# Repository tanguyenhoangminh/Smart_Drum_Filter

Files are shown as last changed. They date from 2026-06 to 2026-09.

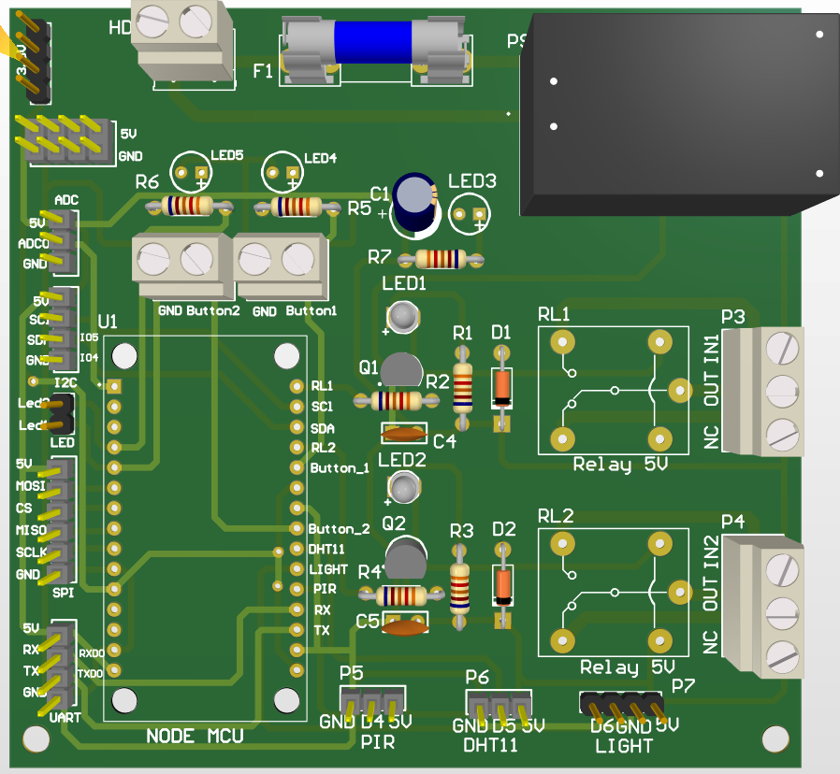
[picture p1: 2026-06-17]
ESP8266_Board/3D_ESP8266.PNG

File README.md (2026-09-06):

With the increasing demand for seafood consumption worldwide, the concept of Aquaculture is increasing, and the need to sustain the quality of water in the RAS has therefore emerged to be a challenge. Of the different types used, the RDF is identified to be one of the most efficient and effective mechanical filters used to remove suspended matter. Yet, the most efficient ones are relatively pricey, and there are no open-source options currently available for the small-scale implementation that the project addresses. The project, therefore, aims to design and implement the Smart Rotary Drum Filter and IoT-Based Control System. The system will make use of the ESP32 microcontroller, which will enable the automated backwashing process depending upon the real-time levels obtained from sensors and the programmed timer. Moreover, the system will also enable remote controlling and monitoring through the use of a mobile app, thereby increasing efficiency and minimizing the manpower aspect.

Keywords: RAS, RDF, Suspended Solids Removal, IoT-based Control, ESP32 Microcontroller, Automated Backwash, Remote Monitoring.

Results: https://drive.google.com/drive/folders/11fJMgWJ-M6j9aROdzN4QvXYW24VE6Z2o?usp=sharing

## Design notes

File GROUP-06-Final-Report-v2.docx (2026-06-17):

VIETNAM NATIONAL UNIVERSITY – HO CHI MINH CITY

INTERNATIONAL UNIVERSITY

SCHOOL OF ELECTRICAL ENGINEERING

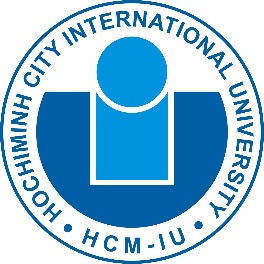
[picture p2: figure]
20070526074003!Logo-HCMIU

CAPSTONE DESIGN 2

SMART DRUM FILTER

Submitted By Group 06:

ta nguyen hoang minh - eeeeiu22084

le duc minh - eeeeiu22074

le Huu thang - eeeeiu22081

vuong thanh tung - eeeeiu22079

nguyen van vinh - eeaciu22174

Ho chi minh city, vietnam
May 26

SMART DRUM FILTER

SUBMITTED BY

TẠ NGUYỄN HOÀNG MINH – EEEEIU22084

LÊ ĐỨC MINH – EEEEIU22074

LÊ HỮU THẮNG – EEEEIU22081

VƯƠNG THANH TÙNG – EEEEIU22079

NGUYỄN VĂN VĨNH – EEACIU22174

Under the guidance and approval of the committee, and approved by its members, this report has been accepted as part of the requirements for Capstone Design 2.

Approved by:

________________________________
Chairperson

________________________________
Committee member

________________________________Committee member

________________________________
Committee member

________________________________
Committee member

________________________________
Committee member

# HONESTY DECLARATION

We, the undersigned members of Group 06, would like to declare that, apart from the acknowledged references, this report does not use language, ideas, or other original material from anyone else; and has not been previously submitted to any other educational or research programs or institutions. We fully understand that any content in this report that contradicts the above statement will automatically lead to the rejection of our Capstone Design 2 project by the School of Electrical Engineering, International University – Vietnam National University Ho Chi Minh City.

Date: 29/05/2026

Full name | Student ID | Signature
Ta Nguyen Hoang Minh | EEEEIU22084 | __________________
Le Duc Minh | EEEEIU22074 | __________________
Le Huu Thang | EEEEIU22081 | __________________
Vuong Thanh Tung | EEEEIU22079 | __________________
Nguyen Van Vinh | EEACIU22174 | __________________

# TURNITIN DECLARATION

Names of the students: Ta Nguyen Hoang Minh, Le Duc Minh, Le Huu Thang, Vuong Thanh Tung, Nguyen Van Vinh

Date: 29/05/2026

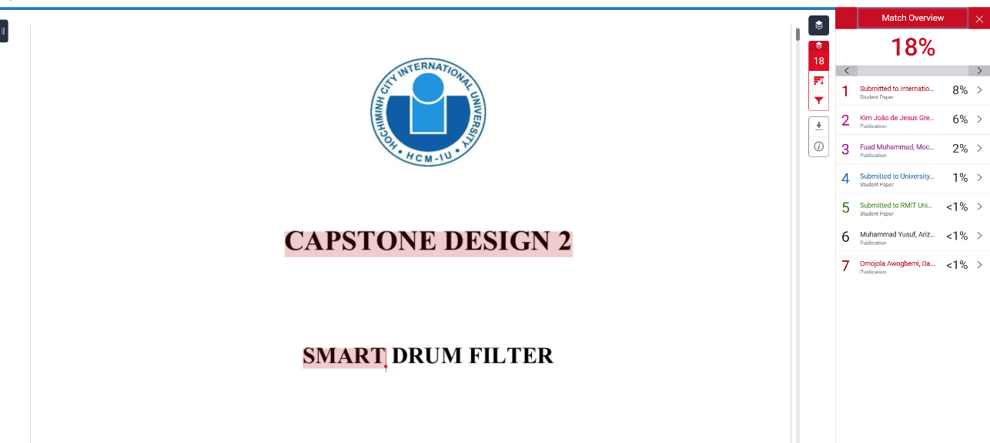
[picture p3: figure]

Advisor Signature Group Leader Signature

(on behalf of the group)

(Signature) (Signature)

__________________ __________________

M. Eng. Vo Minh Thanh Ta Nguyen Hoang Minh

Date: 29/05/2026 Date: 29/05/2026

# ACKNOWLEGMENTS

We, the members of Group 06, would like to express our sincere gratitude to M. Eng. Vo Minh Thanh for his invaluable guidance, encouragement, and support throughout the completion of our Capstone Design 2 project. His professional mentorship and insightful feedback consistently inspired us to improve and overcome challenges during the development process.

We also wish to thank the faculty and staff of the School of Electrical Engineering, International University – VNU-HCM, for providing us with the academic foundation and resources to carry out this project successfully.

# TABLE OF CONTENTS

# LIST OF TABLES

# LIST OF FIGURES

# ABBREVIATIONS AND NOTATIONS

AC Alternative Current

AES Advanced Encryption Standard

AP Access Point

BOD Biochemical Oxygen Demand

DC Direct Current

FAO Food and Agriculture Organization of the United Nations

GPIO General Purpose Input/Output

H Height

HTTP Hypertext Transfer Protocol

IoT Internet of Things

L Length

NAT Network Address Translation

PCB Printed Circuit Board

PSK Pre-Shared Key

RAS Rotary Aquaculture System

RDF Rotary Drum Filter

RL Relay

VAC Root-mean-square Voltage

W Width

Wi-Fi Wireless Fidelity

WPA Wi-Fi Protected Access

# ABSTRACT

With the increasing demand for seafood consumption worldwide, the concept of Aquaculture is increasing, and the need to sustain the quality of water in the RAS has therefore emerged to be a challenge. Of the different types used, the RDF is identified to be one of the most efficient and effective mechanical filters used to remove suspended matter. Yet, the most efficient ones are relatively pricey, and there are no open-source options currently available for the small-scale implementation that the project addresses. The project, therefore, aims to design and implement the Smart Rotary Drum Filter and IoT-Based Control System. The system will make use of the ESP32 microcontroller, which will enable the automated backwashing process depending upon the real-time levels obtained from sensors and the programmed timer. Moreover, the system will also enable remote controlling and monitoring through the use of a mobile app, thereby increasing efficiency and minimizing the manpower aspect.

Keywords: RAS, RDF, Suspended Solids Removal, IoT-based Control, ESP32 Microcontroller, Automated Backwash, Remote Monitoring.

# CHAPTER I - INTRODUCTION

In this chapter, there are three main sections: Issue, Problem Statements, Goal and Objectives. The first section considers the current problem concerned, the second section provides solutions for the first section, and the last one gives out expected goal and objectives needed to be carried out to complete the goal.

## 1. Issue

This part will analyse the causes of water pollution issues in aquaculture, which lead to the aquatic species mortality such as shrimp, fish....

### 1.1. The causes of water pollution in aquaculture

Aquaculture, the farming of aquatic organisms, has been the agro-industrial activity with the highest growth rate worldwide in the last four decades [1]. From 1970 to 2008 the production of aquaculture organisms grew at a rate of 8.3% per year, compared to less than 2% of fisheries, and 2.9% of livestock [1]. The annual aquaculture production is at present over 60 million tons (including marine plants), with an approximate value of 85 billion dollars. The FAO report (Fig.1) revealed that the world population increased by 6.3% from 2004 to 2009, whereas the production of aquatic organisms by aquaculture increased by 31.5% in the same period [1].

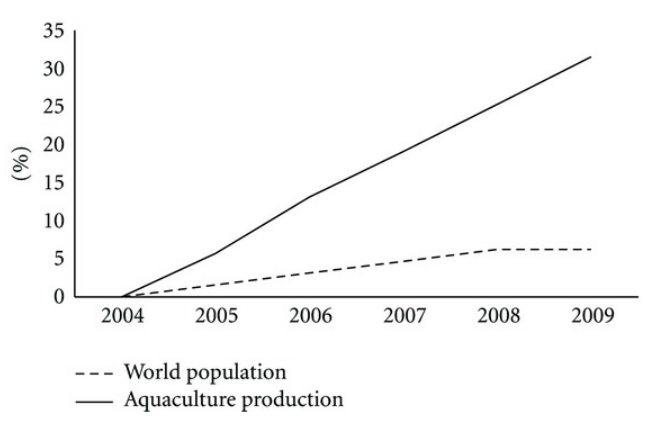
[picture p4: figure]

Figure 1: Compares the percentage of annual increase of world population and aquaculture production, considering year 2004 as the basepoint [1]

In recent years, fisheries and aquaculture production has reached record levels, with total production from 2022 reaching 223.2 million tonnes, of which aquaculture for the first time surpassed natural fishing, reaching 130.9 million tonnes and accounting for more than half of the total aquatic animal production [2]. This growth reflects the increasingly important role of aquaculture in meeting global food and nutrition needs, as per capita consumption has increased at 9.1 kg/year (1961) up to 20.7 kg/year (2022) [2]. However, developing rapidly in aquaculture also led to many factors many factors causing environmental changes on an increasingly large and diverse scale.

Waste from aquaculture includes sludge containing feces from aquatic species such as shrimp and fish, decaying and decomposed leftover feed, residues of materials used in aquaculture such as chemicals, lime and minerals like diatomite, dolomite, and sulfuric deposits, and toxic substances found in acidic soil. This waste is a product of anaerobic decomposition in water, and includes sediment deposited in aquaculture ponds during cleaning and dredging. Farming models with high stocking densities, such as intensive and industrial farming, generate even larger amounts of waste and have a greater impact on environmental pollution [3].

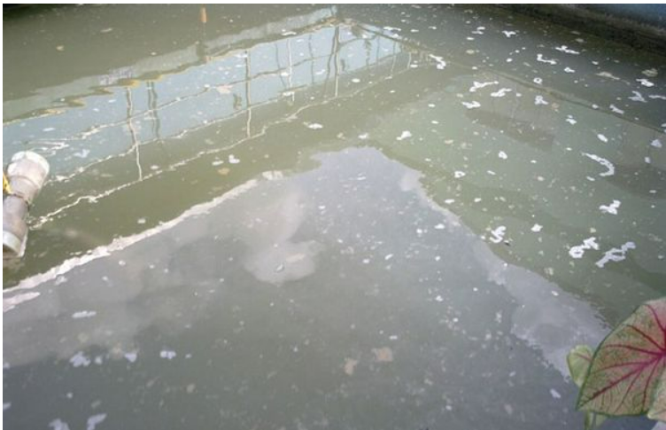
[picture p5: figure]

Some research results show that only 17% of the dry weight of feed supplied to aquaculture ponds is converted into biomass; the rest is released into the environment as manure and decaying excess organic matter [3]. For industrial ponds, waste can contain over 45% nitrogen and 22% other organic matter [3]. High levels of nitrogen and phosphorus in the waste cause eutrophication, leading to the growth of toxic algae in aquaculture environments [3]. This waste spreads rapidly in cage fish farming systems on rivers, and in cage fish farming in flooded wetlands... along with the spread of sediment, which can cause environmental pollution and aquatic diseases [3]. Besides that, the external environmental factors such as weather, waste from industrial production and processing, and domestic wastewater from residential and urban areas also contribute to affecting water quality in aquaculture, leading to more serious environmental pollution and causing significant economic and ecological damage.

Figure 2: Aquaculture ponds showing signs of organic pollution: turbid water, floating scum, reflecting surrounding construction [3].

The consequence of poor water quality and pollution include mass fish and shrimp mortality in coastal areas, which has occurred for many years. This has led to many shrimp farmers and some large-scale shrimp farming businesses to face financial ruin due to debt and bankruptcy. Furthermore, when seafoods get diseased, the consumers have to face with some risks such as exposure to antibiotic residues, antibiotic-resistant bacteria, and reduced nutritional quality. This not only affect human health, but also contributes to antibiotic resistance, and reduce confidence in the safety of food from sea.

### 1.2. The problem with water pollution in aquaculture

#### 1.2.1. Waste generation and treatment in aquaculture

Aquaculture systems generate significant amounts of biological waste, primarily from leftover feed, fish feces, and dissolved nutrients derived from feed and fish metabolism. According to A. B. Dauda, A. Ajadi, A. S. Tola-Fabunmi, and A. O. Akinwole, fish feces contain 3.6–35% Nitrogen (N) and 15–70% Phosphorus (P), while excretory products contribute an additional 37–72% N and 1–62% P [4]. These waste components accumulate in aquaculture ponds as organic-rich sediments and dissolved nutrient loads [4]. The accumulation of these substances increases BOD, disrupts water chemistry, and leads to oxygen depletion [4]. It also causes changes in microbial and plankton populations, increasing the risk of eutrophication and degrading pond bottom quality [4]. These changes negatively affect fish health, reduce pond productivity, and impair ecosystem services [4]. Although farmed fish can tolerate certain nutrient concentrations, the discharge of untreated wastewater into natural water sources can seriously affect surrounding aquatic life [4].

#### 1.2.2. External factors affecting the water environment in aquaculture

Besides internal waste from the farming system, aquaculture is also seriously affected by external factors such as industrial, agricultural, and domestic wastewater, and climate change. These sources of waste often carry heavy metals, toxic chemicals, pesticides, and organic matter, altering environmental parameters such as pH, salinity, and dissolved oxygen content, thereby degrading water quality in the ponds.

Agricultural waste, including pesticides, chemical fertilizers, and herbicides, can be washed into ponds, poisoning aquatic organisms [5]. If not treated promptly, these chemicals can cause mass mortality and degrade the farming environment [5].

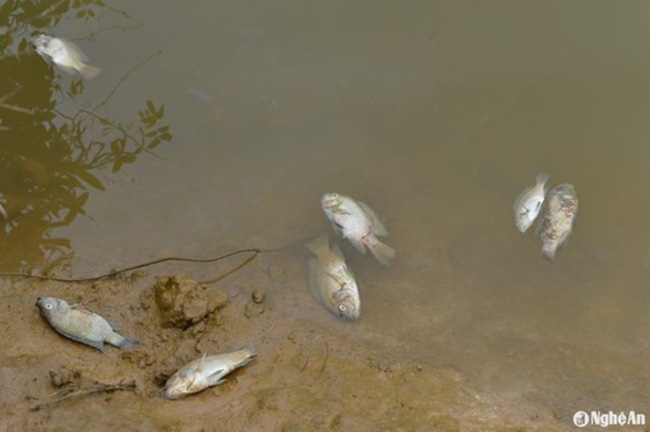
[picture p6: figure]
Ô nhiễm môi trường nước làm tôm cá chết.

Industrial wastewater from food processing, seafood processing, paper, and dyeing factories often contain heavy metals, toxic chemicals, and organic matter. In Hanoi, it has been observed that approximately 350,000–400,000 m³ of wastewater and over 1,000 m³ of solid waste are discharged daily, but only about 10% is treated [6]. The remainder is discharged directly into rivers and streams, causing serious pollution and leading to mass fish deaths in West Lake, affecting six inner-city districts [6]. In Ho Chi Minh City, the Thanh Luong industrial cluster is a prime example, with approximately 500,000 m³ of wastewater per day from detergent, paper, and dye factories [6].

Figure 3: Fish dead by water pollution in aquaculture [6]

Climate change is also a worrying external factor. Changes in temperature, pH, and dissolved oxygen levels in water exceed the tolerance threshold of aquatic life, causing stress or death [7]. Simultaneously, these factors increase the toxicity of certain compounds such as NH₃, H₂S, NO₂, etc., creating favourable conditions for disease development [7]. Without close monitoring and the application of appropriate technical measures, the risk of disease outbreaks and spread is very high, leading to mass fish deaths and water pollution in aquaculture ponds due to decomposing carcasses.

## 2. Problem Statement

To solve one part of these problems: how to remove the waste generated during aquaculture. Our group will design a drum filter system that can effectively remove solid waste such as fish feces, leftover feed, and organic matter before they accumulate and degrade water quality.

## 3. Goal And Objectives

### a. Goal

To design and develop a smart drum filter system capable of remote control and monitoring to optimize operational costs.

### b. Objectives

  - Objective 1:

To design the overall system architecture, focus on the mechanical structure (drum, supporting frame, and water flow system…).

- Task 1.1: Design the mechanical structure – drum, supporting frame, housing
- Task 1.2: Searching and select suitable materials – mesh size, cleaning pump, motor.
- Task 1.3: Assemble the prototype
  - Objective 2:

To develop and implement the electric-controllable system

- Task 2.1: Develop a hardware that using microcontrollers for remote control and monitoring.
- Task 2.2: Coding and integrating the electronic circuit into the drum filter system

# CHAPTER II - DESIGN SPECIFICATIONS AND ENGINEERING STANDARDS

## 2.1. Design Specifications

Drum Cross-sectional Area: P=πr^2 =π(0.11)^2 =0.0121π (m^2 )

Volume of the Rotatable Strainer :

V=430×390×370×10^(-9) =0.062049 m^3 (=62.049 l)

Flow Velocity: v=Q/A=5/(0.0121π)≈131.533 m/h=0.036 (m^3)/s

Retention Time: t=V/Q=0.062049/5=0.0124098 h=44.67528 s

Deposition Rate: R_d =k_d CA=10^(-7) ×0.0121×π×C=121×10^(-11) πC

- C is concentration of cultured species ((kg)/(m^3))

## 2.2. Engineering Codes and Standards

Table 1: Engineering Codes and Corresponding Standards

Element/Product/System | Engineering Standards | Comments
4058Z-555 Motor | IEC 60034-1 | Defines the physical performance and rating for rotating DC machines.
ESP8266 NodeMCU | IEEE 802.11 b/g/n | Wi-Fi 2.4GHz communication protocols.
Pump (OEM) | IEC 60529 | The international standard that defines the testing for its IP68 submersible rating.
Songle Relay | IEC 61810-1 | The core standard for low-voltage electromechanical relays
Float Sensor (OEM) | IEC 60529 | Defines the IP68 waterproof enclosure rating for the plastic housing and seal.
Power Supply | IEC 60950-1 | The legacy standard that generic metal-mesh power supplies are modeled after.

## 2.3. Realistic Constraints

Table 2: Realistic Constraints

Area | Realistic Constraints
Economicity | <200 USD – Cost-effective materials and minimum electric components
Environment | - Sound: Mechanical actuators and fluid pumps generate acoustic noise that may be disruptive in isolated or quiet environments. - Aquatic: Submerged operational components require durable, non-toxic, and corrosion-resistant materials to prevent water contamination. - Ecological: System design necessitates the use of RoHS-compliant electronics and recyclable structural frame materials. - Aerial: Brushed DC mechanical actuators emit trace carbon dust particulates during extended operation.
Health and Safety | Inherent risk of electrical shock when integrating low-voltage sensory circuits with high-voltage mains power in wet environments. Potential fire hazards exist due to improper thermal management or unregulated power supplies driving continuous-duty microcontrollers.
Manufacturability | Supply chain reliance on imported semiconductor fabrication for wireless IoT communication modules. Ensuring consistent waterproof sealing (IP68) and mechanical tolerance reliability during the assembly of submerged electromechanical sensors.
Sustainability | Electromechanical sensors and mechanical relays possess a finite operational lifespan due to physical wear and contact degradation. While automation reduces physical waste, the demand for specialized electronic circuit maintenance increases.
Ethicality | Global environmental and labor implications concerning the extraction of raw materials required for semiconductor manufacturing. Potential data privacy vulnerabilities regarding unauthorized access to connected IoT management dashboards and sensor telemetry.
Social | System automation significantly reduces manual maintenance labor, promoting overall operational efficiency. However, a strict reliance on web-based IoT interfaces and digital dashboards may alienate end-users with limited technical literacy.
Political | Global trade regulations, tariffs, and semiconductor export restrictions impacting the procurement of wireless communication modules. Mandatory compliance with regional electrical safety directives (e.g., Vietnam TCVN, IEC standards) for safe domestic or industrial deployment.
Measurement | Dimensions: 430 (L) x 390 (W) x 370 (H) mm Weight: <6 kg - Portable

# CHAPTER III - PROJECT MANAGEMENT

## 3.1. Budget and Cost Management Plan

This part includes a details description about how cost of the project may be managed, listed with all the required components and devices.

Table 3: Table of Estimated Costs.

Item | Description | Quantity | Unit Price (USD) | Total Cost (USD)
MCU | ESP8266 NodeMCU Modded (Micro USB) | 1 | $2.99 | $2.99
Sensors | Float Switch 40cm (OEM) (2 wire, 110 V - 220 VAC, deactivate threshold 10MΩ, 20-80 Celcius operational threshold) | 1 | $1.82 | $1.82
Relay | SRD-05VDC-SL-C | 2 | $0.33 | $0.66
Motor | 4058Z-555 | 1 | $8.16 | $8.16
Pump | DC 12V/24V Brushless Submersibe Pump (800L/H, 5m lift) | 1 | $6.96 | $6.96
Board | PCB (Green) manufactures | 1 | $2.09 | $2.09
Frame | PP, PVC, manufactures | 1 | $120 | $120
Miscellaneous | Screws, adhesive, headers, etc. | - | $10.00 | $10.00
Total Estimated Cost (Exclude Shipment fees) | | | | $152.68

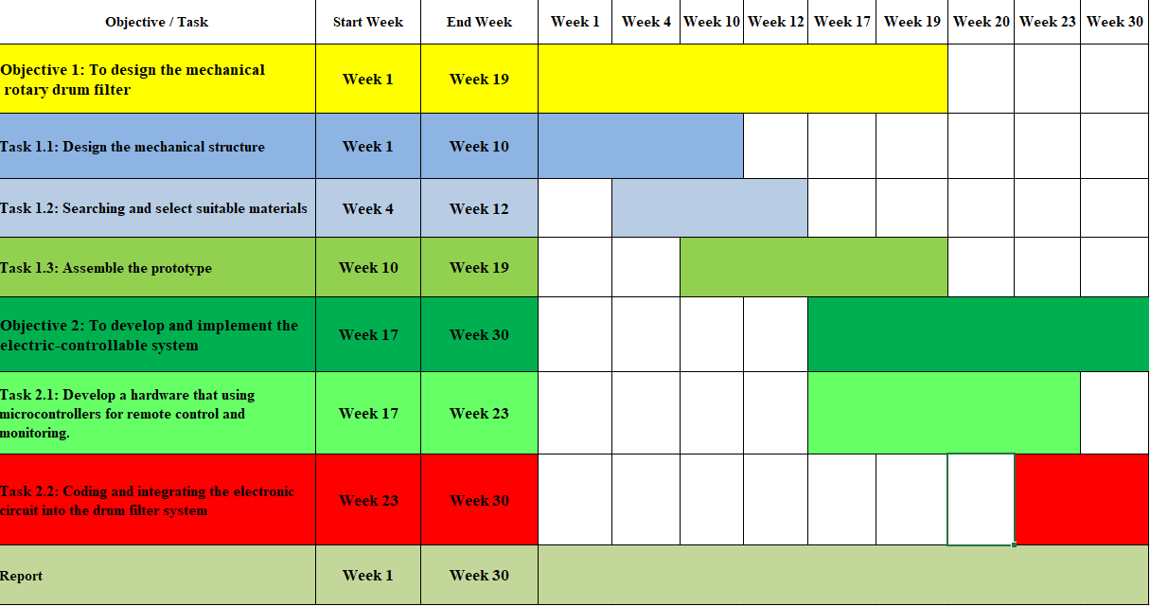
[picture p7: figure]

## 3.2. Project Schedule

Figure 4: Gantt Chart for Project Schedule

## 3.3. Resource Planning

Table 4: Resource Planning for Project

Number | Full name | Student ID | Role | Tasks
1 | Tạ Nguyễn Hoàng Minh | EEEEIU22084 | Group Leader | Management group's work, writing report, design the mechanical structure, coding and integrating
2 | Lê Đức Minh | EEEEIU22074 | Member | Writing report, assemble the prototype, verify and perform product
3 | Lê Hữu Thắng | EEEEIU22081 | Member | Coding and integrating, design the mechanical structure, verify and perform product
4 | Nguyễn Văn Vĩnh | EEACIU22174 | Member | Develop the hardware, assemble the prototype, verify and perform all tests
5 | Vương Thanh Tùng | EEEEIU22079 | Member | Writing report, Presentation slide, Searching for materials

# CHAPTER IV - LITERATURE REVIEW

Following a review of articles related on drum filter innovations in aquaculture, it is identified with several studies that are particularly relevant to the project. Initially, the first study case, “Optimizing community-based aquaponics: Evaluating the impact of rotary drum filter implementation on water conservation and operational efficiency” (2025) [8], shows the efficiency of the rotary-typed drum filters along the general parameters for such choice, while the second, “Effect of drum filter mesh size on RAS water quality” (2025) [9], implemented with the mesh size comparison over their specific treatment efficiency. Additionally, it may be profound that integration of a microcontroller is used to compatibly communicate between analogue encounter and the toggle of the system’s function through digital platform and it is entirely entitled to is “ESP32 Based Implementation of Water Quality and Quantity Regulating System” [10].

## 4.1. Optimizing community-based aquaponics: Evaluating the impact of rotary drum filter implementation on water conservation and operational efficiency [8]

In this study case the researchers were investigating the application of rotary drum filter in aquaponic system (combine between aquaculture and hydroponics). The rotary drum filter utilized in this study is equipped with several technical specifications designed to optimize efficiency in water filtration process in Table 5.

Table 5: Filtration Specifications

Filtration Component | Specification
Type | Rotary Drum filter
Water Flow | Max. 5m³/h
Cleaning Pump | 80W
Drum Motor | 15W
Screw Mesh | 200 mesh, SS 316 material
Water inlet | 32 mm x 2
Water outlet | 40 mm x 2
Sewage Outlet | 32 mm
Body Dimensions | 430 x 390 x 370 mm
Roller Diameter | 220mm
Roller Length | 200mm
Screw Material | SS316L
Case Material | PP

Based on several months of operational experience in the community, the researchers concluded that alternative from RDF would provide significant benefits on environment, technique, and finance. But more notable improvement was the complete elimination of routine water replacement, resulting in full reductant as water use. This translates into substantial cost savings and improved system sustainability.

Additionally, the RDF consistently maintained high water quality to avoid water population in aquaculture by the incessant removal of most impurities and suspended solids. This automated filtration process also reduced labour needs, minimizing the time required for manual cleaning and monitoring of the system. However, the high cost to investment for rotary drum filter, which relatively high energy consumption due to continuous drum rotation and backwashing. Besides that, the devices like timer and cleaning pump can consume amount of power so it can be reducing operational flexibility Not only that as it requires strong and precision mechanical component because these components must be under the water in long-term. Notwithstanding, these disadvantages are not too significant and can be overcome by using smart integrated electronic devices.

## 4.2. Effect of drum filter mesh size on RAS water quality [9]

The research paper shows that the system of RAS with drum filter, inseparable with a role in recirculating aquaculture systems by removing suspended solids production subject, is partial for its optimization of performance due to the fact that it directly affects water quality as well as investment and operating costs. The most from significant parameters influencing drum filter performance is the mesh size of the filter screen. The study investigated using three divergent stainless steel mesh categories by 70-45-30 (µm) in size and a control system apart from rotary encasement to filtration, applying an eight-week trial with all treatments run in triplicate [9].

In this experiment, all systems were set up to operate under the same conditions, and added make-up water no such additional, was despite backwashing. This allowed the researchers to isolate the effect of mesh size on water quality.

Table 6: 8-week FCRs data and Water Quality parameters (3-week trial average data – full replicating)

Treatment | Control | | 70um | | 45um | | 30um
Empty Cell | Average | Std. Dev. | Average | Std. Dev. | Average | Std. Dev. | Average | Std. Dev.
Nitrate (mg NO3-N l−1) | 43.3 | 1.2 | 40.1 | 1.7 | 40.1 | 1.3 | 40.4 | 0.4
Nitrite (µg NO2-N l−1) | 193.6 | 47.8 | 268.2 | 37.2 | 136.3 | 28.7 | 167.5 | 30.1
Ammonium (µg NH4-N l−1) | 120.9 | 1.1 | 109.7 | 15.3 | 90.6 | 7.1 | 84.2 | 5.9
Orto-phosphate (mg PO4-P l−1) | 1.60 | 0.12 | 1.29 | 0.08 | 1.13 | 0.07 | 1.14 | 0.12
Total phosphate (mg PO4-P l−1) | 1.83 | 0.15 | 1.49 | 0.03 | 1.24 | 0.08 | 1.24 | 0.14
Num. of particles (million ml−1) | 2.89 | 1.51 | 2.19 | 0.90 | 1.14 | 0.64 | 1.27 | 0.69
Vol. of particles (mm3 ml−1) | 0.026 | 0.007 | 0.012 | 0.004 | 0.099 | 0.007 | 0.008 | 0.005
S. A. of particles (mm2 ml−1) | 27.7 | 9.0 | 21.9 | 3.9 | 13.0 | 6.8 | 12.7 | 5.7
β value | 3.87 | 0.12 | 4.44 | 0.21 | 4.17 | 0.37 | 4.31 | 0.22
Turbidity (FNU) | 6.3 | 1.7 | 3.4 | 0.9 | 2.4 | 0.6 | 2.5 | 0.6
UV transmission (%) | 55.3 | 3.1 | 53.9 | 1.2 | 56.3 | 1.7 | 55.5 | 1.9
H2O2 (k−1) | 0.72 | 0.28 | 0.50 | 0.15 | 0.36 | 0.21 | 0.35 | 0.13
Bactiquant | 82862 | 27861 | 63039 | 26531 | 60318 | 41990 | 57405 | 25994
BOD5-Tot (mg l−1) | 6.66 | 1.25 | 5.04 | 0.82 | 3.39 | 1.00 | 3.53 | 0.81
BOD5-Diss (mg l−1) | 1.29 | 0.21 | 1.33 | 0.19 | 1.40 | 0.25 | 1.25 | 0.18
BOD5-Part (mg l−1) | 5.37 | 1.22 | 3.71 | 0.84 | 2.00 | 1.06 | 2.29 | 0.82
CODTot (mg l−1) | 36.5 | 3.1 | 33.1 | 1.4 | 28.6 | 1.9 | 29.1 | 1.8
CODDiss (mg l−1) | 25.0 | 1.8 | 27.9 | 1.0 | 26.0 | 0.9 | 26.4 | 1.2
CODPart (mg l−1) | 11.5 | 2.6 | 5.2 | 1.3 | 2.6 | 1.4 | 2.7 | 1.0
FCR | 0.86 | 0.02 | 0.85 | 0.02 | 0.79 | 0.02 | 0.82 | 0.01

Based on the results (Table 6), the research demonstrated that mechanical filtration significantly improved water quality parameters compared to the control. Reducing the size of the mesh at the number that in the range of 70-45 (µm) has repulse to the result of noticeable advances in most collating categories, including ammonium, nitrite, phosphate, turbidity, and particle count. However, restrain the mesh size down to 30 micrometres did not provide additional improvement in water quality. Instead, it increased operational costs due to more frequent backwashing and reduced flow capacity. This experiment demonstrates that a filter mesh with a size of 45 µm is the most effective.

The study also highlighted that while smaller mesh sizes improve the removal of fine suspended solids, extremely small meshes can cause practical problems. These include reduced water flow, a higher chance of clogging, increased particle breakage, and more frequent cleaning cycles. Such issues lead to greater energy consumption, higher water usage, and more maintenance. Therefore, choosing a suitable mesh size requires balancing filtration efficiency with long-term system stability and operating cost.

## 4.3. ESP32 Based Implementation of Water Quality and Quantity Regulating System [10]

Following the articles, the research groups propose a model using to monitor the water quality and quantity of elevated reservoirs in cities, residential areas, universities, and other locations. It is decided to use iOT method by using the microcontroller ESP32 with Blynk to communicate data with the help of a phone/PC. Water quality is monitored by the various parameter of chemical on water like pH and electrical conductivity and parameter of physical on water like temperature and turbidity. Based on the evaluation of these authors, ESP32, which is used in this work has the advantages of low cost, high frequency, and built-in sensors (temperature, hall effect sensors like touch sensors), both WAN and PAN integrations are present, speed up to 150 megabit per second, ten pin ADC, module of power management, low-noise amplyfing receiver, security, filtering, etc. and install easily. Besides that, the researchers also integrated some sensors so that it can easily be monitoring water quality and quantity. Eventually, there is Figure 5 to show the flowchart of how the circuit function.

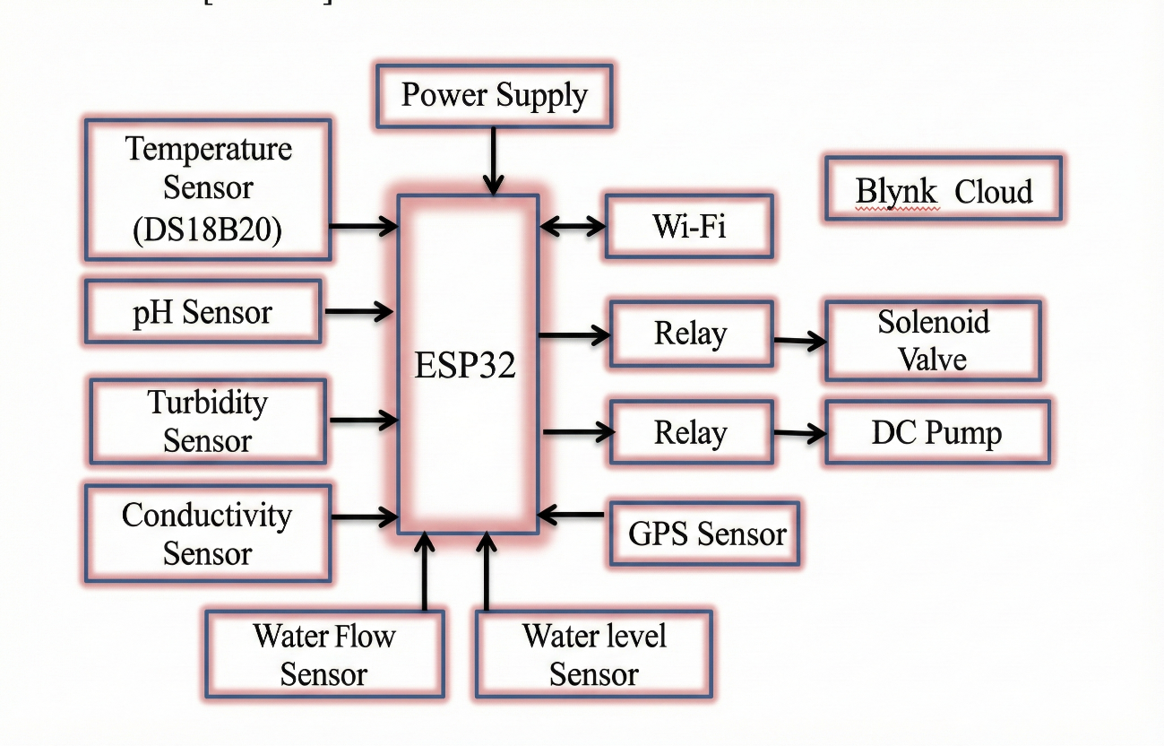
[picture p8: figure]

Figure 5: Architecture of Water Quality and Quantity Regulating System using ESP32

Additionally, this studies case has presented the use of microcontrollers combined with Wi-Fi modules to monitor and control water supply systems. Specifically, the water level in the tank is measured by sensors, when the water level falls below the allowable threshold, the solenoid valve and pump will be activated to add water (Fig.6). The measurement data is transmitted to the cloud platform at a predetermined cycle, allowing users to monitor and manage remotely via smart devices. This case study shows that the ESP32 can easily connect and link with other electronic devices, such as various types of sensors and control by using Wi-Fi module. In spite of the fact that sensors were applied to quality monitor such as pH sensors, GPS sensor, but this confirm ESP32 can connect with float switch, relay, DC pump to remote monitor and control.

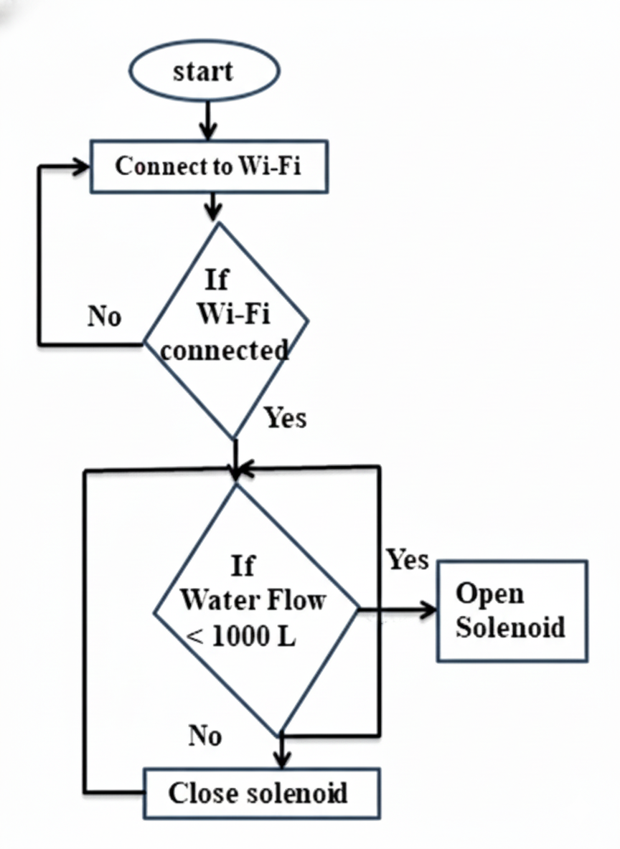
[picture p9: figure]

Figure 6: Wi-Fi connection and Water flow control flowchart

Following the research papers, the results of using ESP32 and Blynk for communication is positive. The effectiveness of this microcontroller is not only easy to connect with other components but also cost-effective and beneficial for monitoring the water quality. Additionally, the ESP32 widely used because it is integrated available Wi-Fi and Bluetooth, low power consumption and cost effectively, eliminating the additional hardware require. Although, the study case is focus on water quality monitor, but this approach shows the potential in integrating iOT technology to remote monitoring and controlling mechanical processes, such as drum filter operation in water treatment systems.

# CHAPTER V - METHODOLOGY

Aiming to improve aquaculture efficiency, minimize environmental impact, and enhance water quality management. The goal of our group is to design and develop a smart drum filter system to remote control and monitoring to reduce waste and operational cost in aquaculture. The methodology included two main objectives. The first one is designing a mechanical structure for drum filter so that it can operation normally by deductive minimize the waste in aqua ponds. The second is develop an electric circuit using ESP32 to remote and monitoring the drum filter.

## 5.1. Objective 1: To design the overall system architecture, focus on the mechanical structure

Task 1: Design the mechanical structure – drum, supporting frame, housing

Based on the rotary drum filter that using in an article "Optimizing community-based aquaponics: Evaluating the impact of rotary drum filter implementation on water conservation", the mechanical structure of the drum filter will be designed with some parameter adjustments.

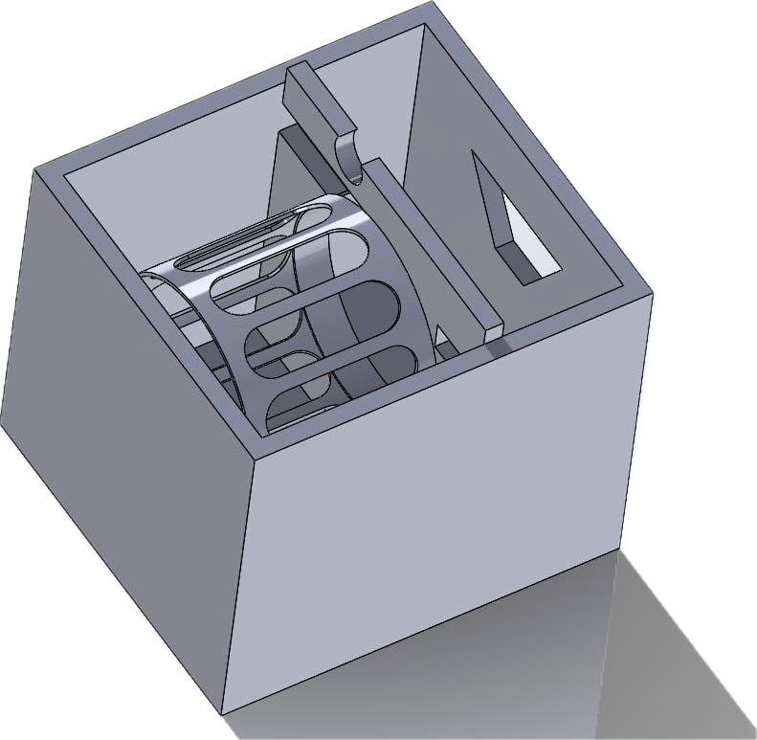
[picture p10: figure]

Figure 7: Completed Frame 3D Design of Drum Filter

The filter drum components are designed in 3D using SolidWorks software, with a body size of 430mm (Length) x 390mm (Width) x 370mm (Height). Additionally, sewage outlet on the body frame has a radius of 32mm, and the water inlet has been adjusted from two 32mm radius holes to one 30mm radius hole. The water outlet has also been slightly modified to two 30mm radius holes.

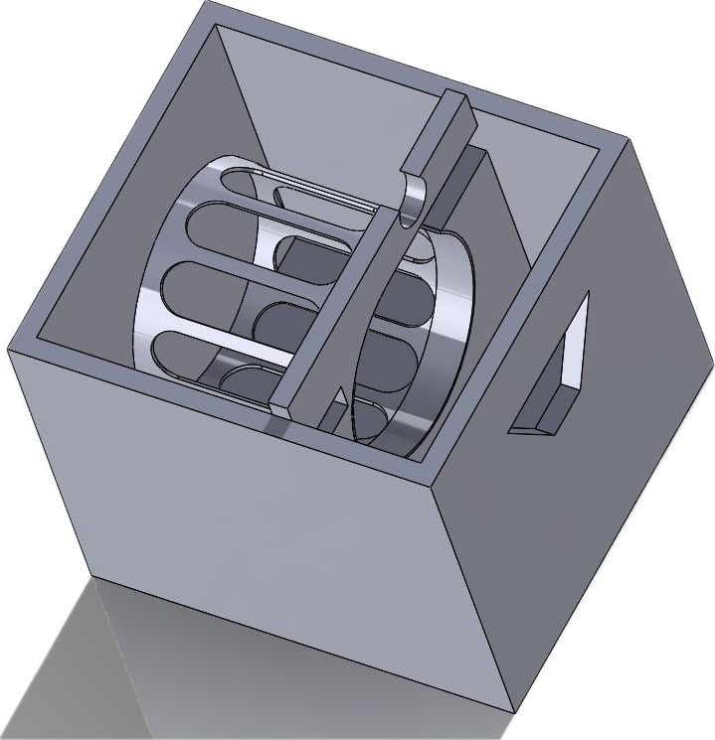
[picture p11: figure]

Additionally, the rotating drum cage has a diameter of 220mm and a length of 250mm. This size was chosen to strike a balance between practicality and performance: it provides a sufficiently large surface area for efficient filtration while keeping the prototype compact and lightweight. The chosen dimensions ensure that the drum can be easily fabricated, meet the motor's torque requirements, and be tested under laboratory conditions without excessive energy consumption.

Figure 8: 3D Design of Drum Cage

Task 2: Searching and select suitable materials – mesh size, cleaning pump, motor

According to the related research (Literature Review 4.2), the result has shown the mesh size of 45µm getting the most significant efficiency of filtering out the toxicity in the term of concentration unit. Therefore, the parameter of mesh size should be in the range from 70µm to 45µm. For the system to be stabled, the mesh size should be 53µm, made from Stainless Steel 316 (Fig.9), ensuring corrosion resistance and durability over extended use.

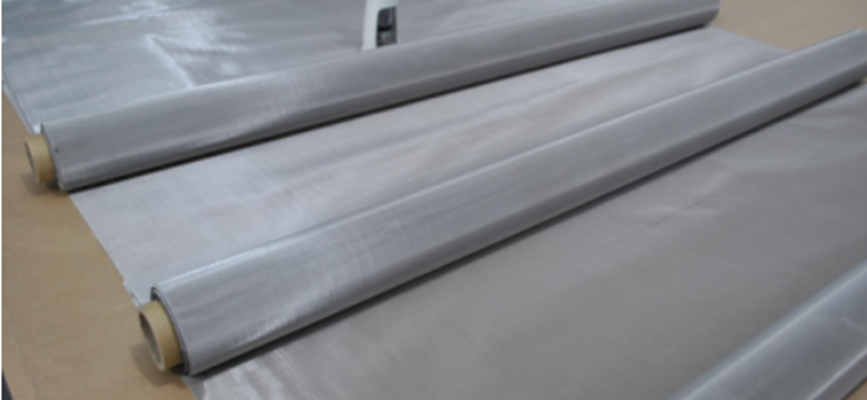
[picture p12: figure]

Figure 9: Illustration of stainless steel 316 [11]

Besides that, Polypropylene (PP) was chosen for the main housing and frame of the drum filter due to its superior chemical resistance and durability in wet environments. Polyvinyl Chloride (PVC) was selected for auxiliary parts such as piping and protective casings, where rigidity and low cost are prioritized.

Task 3: Assemble the prototype

In this task, a prototype rotary drum filter was assembled based on the mechanical structure in Task 1.1 and the components in Task 1.2. For the assembly, the components, drum, frame, motor, and water delivery system were assembled to form a complete system. Additionally, to ensure sturdy and water resistance, several components were used, such as bracing to maintain the slope of the trough and prevent sediment accumulation, stainless steel bolts to securely fix the drum frame, and rubber gaskets to prevent leaks and reduce vibration. Furthermore, the prototype was tested to ensure correct alignment and the ability to filter dirty water.

## 5.2. Objective 2: To develop and implement the electric circuit controllable system

Task 1: Develop a hardware that using microcontrollers for remote control and monitoring.

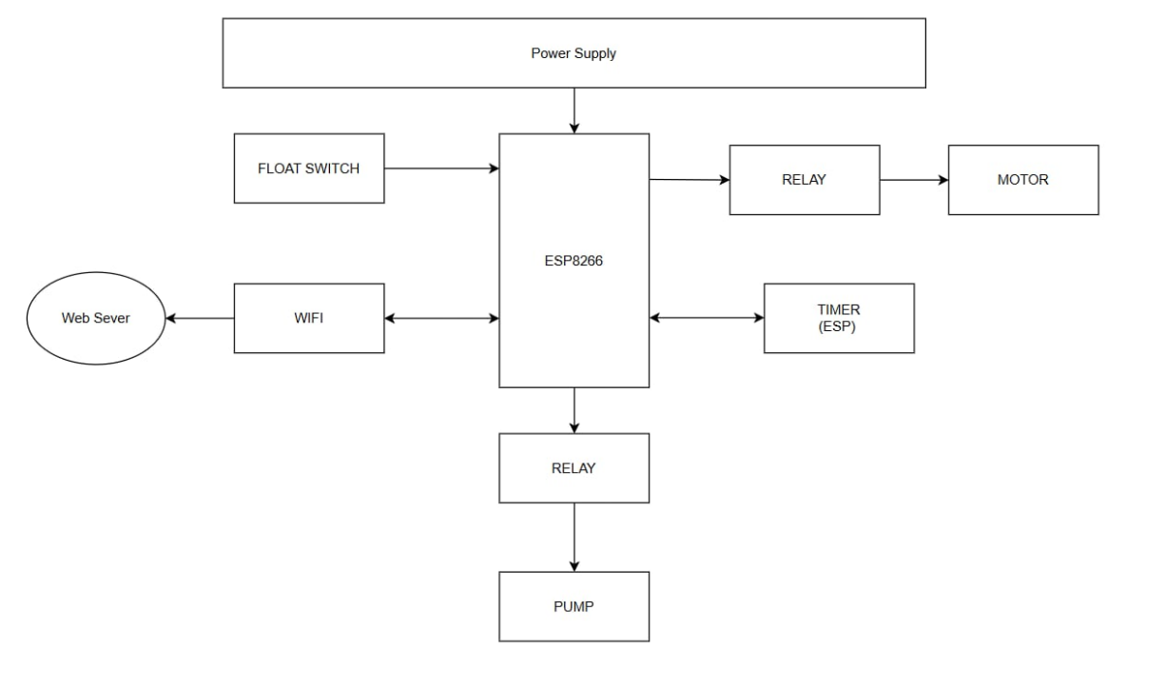
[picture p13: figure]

Figure 8: Flowchart of the electric circuit

In this part, our group will use the ESP8266 as the main microcontroller to enable control and remote monitoring of the system. A float switch will be connected to the ESP8266 through a digital input pin, allowing the microcontroller to detect the water level status. We also establish relay into motor and pump then will be connected to the digital output pins of the ESP8266, and these relays will in turn control external devices such as the pump and the motor. By using relays, the system can safely separate the higher voltage required by the pump and motor from the low‑voltage logic of the ESP8266 which only tolerate below 5V, thus preventing any damage to the microcontroller.

The Wi-Fi module and the timer were integrated into ESP8266. Therefore, through a host web server Blynk, enabling users to monitor the water level and remotely control the pump or motor from a smartphone or computer. The timer functionality will support scheduling or automation tasks, making the system more efficient and reliable.

Task 2: Coding and integrating the electronic circuit into the drum filter system

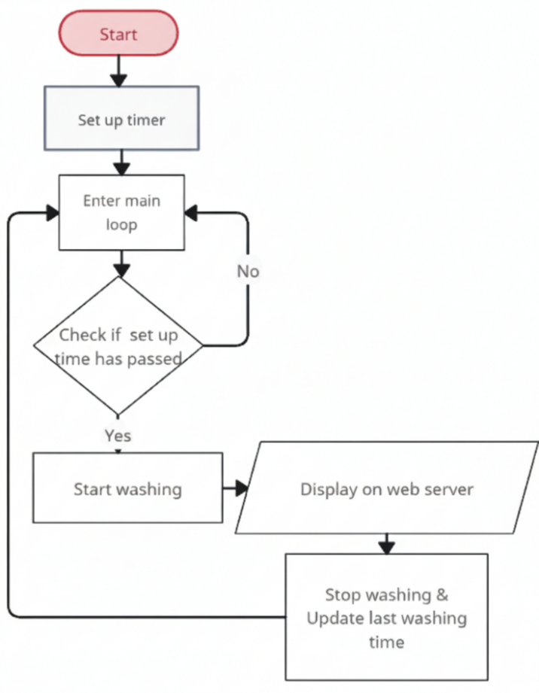
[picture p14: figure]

Figure 9: Flowchart of Programming setup washing schedule

In this section, our group will program a system where the user sets a schedule in advance through a web server “Blynk” for automatic cleaning. When the set time is reached, the system will automatically activate, and the cleaning pump and rotating drum will begin operating. After the cleaning process is complete, the system will update the rinsing time and repeat the process. Besides that, we also code some function to control the motor and cleaning pump. Additionally, the status of rotary drum filter will display on Blynk.console, which interface has many available functions and is easy to use.then we can easily monitor water level.

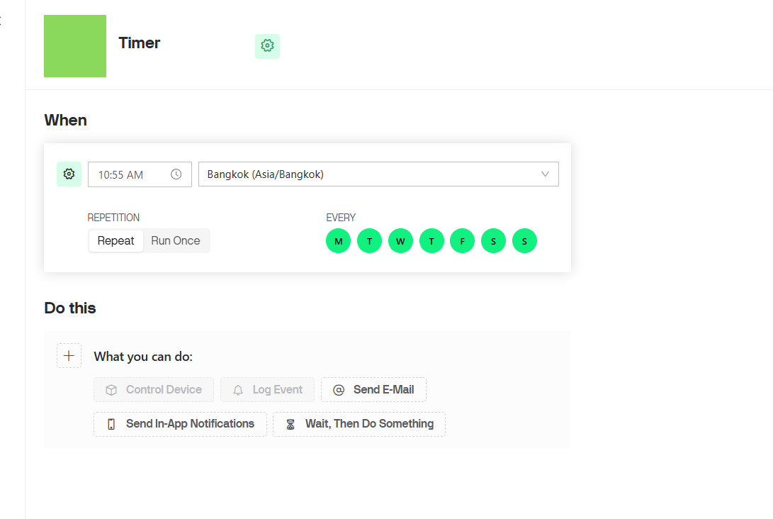
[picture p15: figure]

Figure 10: Timer interface on the Blynk.console

# CHAPTER VI – RESULTS

## 6.1 Results

### Objective 1: To design the overall system architecture, focus on the mechanical structure

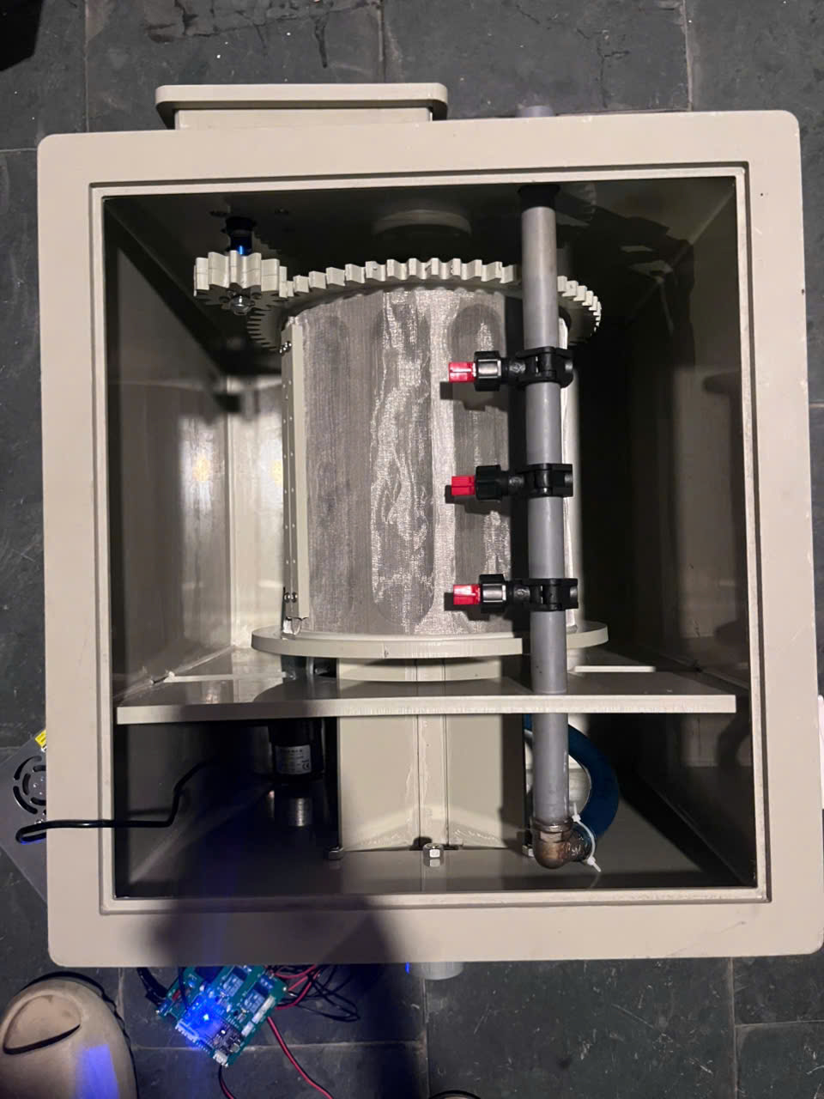
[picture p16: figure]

Figure 11 Smart Drum Filter - General Mechanical Part

In Figure 11, as the matter of verification from Methodology – Part 5, all components have been being assembling and completed. The checklist includes Housing Frame, Rotary Frame and its compatibly functional components. In general, with the required voltage from power regulatory (24V), the filtration affirms the flawlessness in sustenance of operation with the DC Pump and DC Motor.

### Objective 2: To develop and implement the electric circuit controllable system

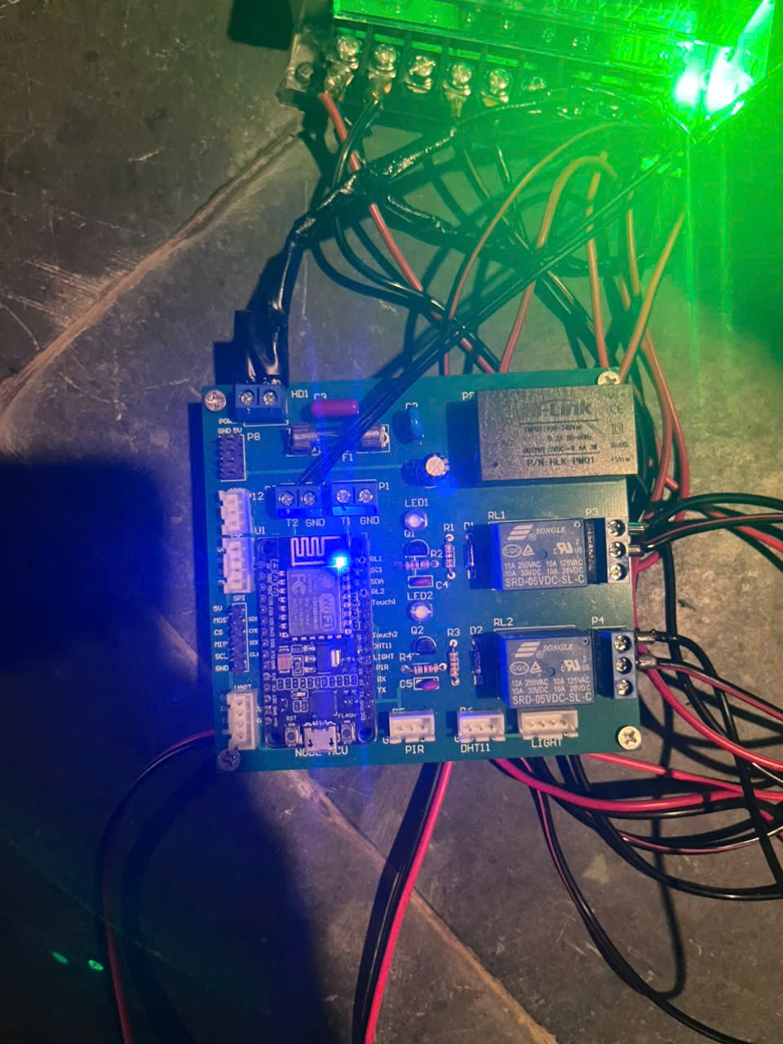
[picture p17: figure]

Figure 12 Smart Drum Filter - Integrated Electrical Component

In Figure 12, Relay 1 (RL1) is used to toggle Pump and Relay 2 (RL2) is Motor. Upon any of these components’ activation, indicators LED1 and LED2 are responsible for Pump and Motor, respectively, in the physical aspect. While in virtual side, the blue-shining indicator (Figure 12) shows in real-time, the status of Wi-Fi connection. This circuit practically uses 220 VAC, so it will not be dependence on the Power Regulator.

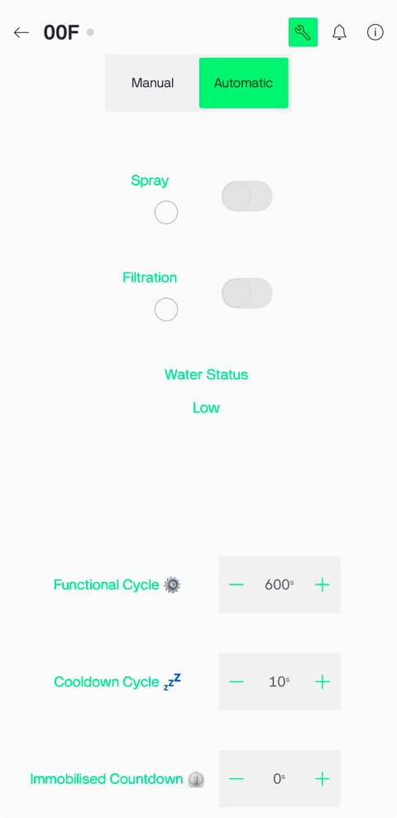
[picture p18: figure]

Figure 13 Control Interface on Blynk

Switching to Virtual Platform, Figure 13 shows User Interface on Blynk console app on Takeaway Device or it can be accessed by Fixed Platform on Devices - Blynk.Console (https://blynk.cloud/dashboard/1049431/global/devices/1533/organization/1049431/devices/3972807/dashboard) using this login certificate Vlimenether101@gmail.com/V1im3n3t43r3o3.

Automatic mode, which includes 3 Timers (seconds):

  - Functional Cycle: set Motor and Pump on (Interval of activating)
  - Cooldown Cycle: set Motor and Pump off (Interval of waiting for the external Pump’s activate)
  - Immobilised Countdown: deactivate all and switching back to Manual mode as the timing ends

This mode only activates under the condition of Water Status: Sufficient

Manual mode:

  - Spray: toggle Pump
  - Filtration: toggle Motor

In Figure 13, the respective indicators under the denotation “Spray” and “Filtration” are the physical feedback of real-time.

This mode’s Water Status is barely a notification but none of constrain to the control and these switches may be disabled if Automatic mode is ON.

Blynk is a global network communication interface, promises with its messaging protocol of the security of TLS 1.2/1.3 certificate, and used for the convenience of remote control. However, within the inference of doubt, here transfers the local-network communicating intersection.

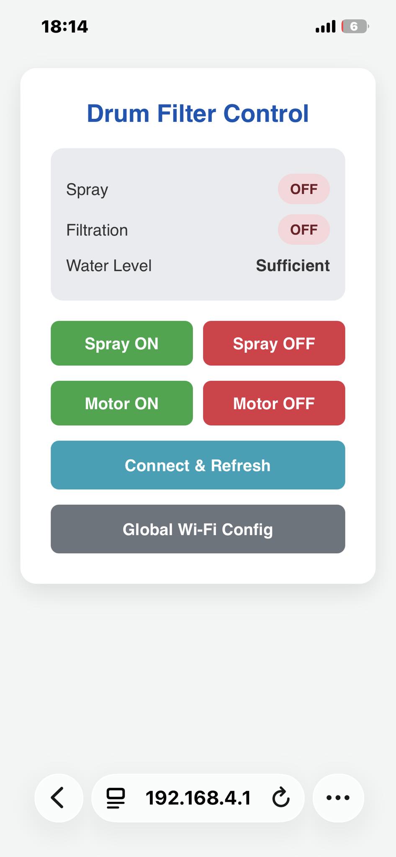
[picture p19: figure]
Không có mô tả.

Figure 14 Control Interface using HTTP protocol

In Figure 14, this interface can also replace as internal control platform and concurrently, network bridging configuration for Blynk. It merely transfers HTTP onto microcontroller over its broadcast AP AES/PSK using login certificate WPA Drum Filter System Configuration/V1im3n3t43r3o3.

Alternatively: http://drumfilter.local / 192.168.4.1

As the matter of security, in spite of unsecured HTTP protocol, this practically is an isolated communication form by the cutout of NAT. Therefore, no global network connection (Usually household Wi-Fi connection) can control (Crash as “No network connection” immediately) and only hold the ability as the fact that the controlling device submits to the previous WPA certificate.

Table 7: Filtration efficiency of smart drum filter operates with various type of fish waste with a stainless stell mesh size is 53µm

Scenerio | Run | Input | Sewage Output (5 minutes) | Filtration efficiency (%)
Fish feeds, (large medium-sized residue, easily disintegrated) | 1 | 1,2g | 1.08g | 90%
| 2 | 1,2g | 1.05g | s87.50%
| 3 | 1,2g | 1.07g | 89.16%
| Average | 1.2g | 1.07g | 89%
Fish Waste / Organic Sludge (Small particles, suspended) | 1 | 20g | 16g | 80%
| 2 | 18.2g | 15.2g | 83,52%
| 3 | 17.6g | 14.1g | 80.11%
| Average | 30g | 15.1g | 81.21%
Mixture | 1 | 23.6g | 14.2g | 60.17%
| 2 | 21.2g | 12.9g | 60.85%
| 3 | 20.4g | 12.4g | 60.78%
| Average | 21.7g | 13.17g | 60.61%

In Table 7, the results show the smart drum filter operate stable and effective with the fish pellets has reached very high residue recovery in 5 minutes about 89%, the filtration can be removed totally the sewage in a long-time range. Besides that, fish waste/organic sludge also retains over 80%, while the simulated mixture maintains a stable efficiency around 60%. This proves that the device has the ability to handle a variety of waste types, particularly effectively with easily settling solid particles and organics.

## 6.2 Discussions

As observed from the result figures, the system demonstrated functional performance across both its mechanical and electronic subsystems. In the control experiment, the collected data from the filtration infirmed the functionality of the system. Two independent remote-control interfaces were confirmed operational: the Blynk mobile application successfully displayed real-time water status and allowed toggling of the Spray and Filtration functions over a cloud connection, while a local web interface provided an alternative control channel via internal-hosted AP, offering manual ON/OFF control for the pump and motor without relying on internet connectivity. The PCB has operated successfully with minimal delay control and error-free over minimal-priced microcontroller ESP8266 and isolated-protecting layer. This design is to be adaptive to control any power continuous actuators and voltage regulator so it is convenience for any replacement or even an upgrade. Furthermore, there are reserved headers for additional sensors indicating the board's expandability for future development and an analogue GPIO of microcontroller is used.

# CHAPTER VII - CONCLUSION AND FUTURE WORK

## 7.1. Conclusions

This project successfully achieved its main objective: designing and implementing an intelligent rotary drum filtration system with an integrated IoT control system. The system utilizes a robust mechanical structure (using 316 53 µm stainless steel mesh) and an ESP8266 microcontroller to efficiently and automatically remove suspended solids from aquaculture water. Leveraging the Blynk platform, users can remotely control the system and seamlessly schedule backwash cycles via smart devices, significantly reducing labour and operating costs. Furthermore, the project was successfully completed within a budget of $200. In conclusion, this intelligent drum filtration system provides a practical, economical, and sustainable solution for recirculating aquaculture systems (RAS), minimizing water pollution and maintaining high water quality.

## 7.2. Future Work

While the current prototype has effectively automated the mechanical filtration process, future improvements could significantly enhance its automation by integrating the external pump onto Automatic mode with real-time turbidity sensor as feedback to optimize operational sustenance (in finance) and optimize the ESP8266 potential of Analogue GPIO integrating with a Wattmeter to record monthly the power consumption of the system.

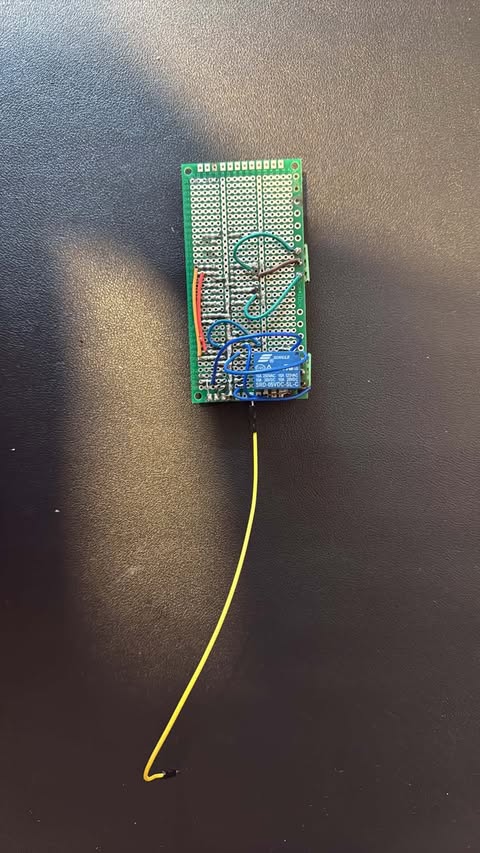
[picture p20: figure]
Mở ảnh

Figure 15 Prototype of addition external Pump control and Wattmeter (Rear view)

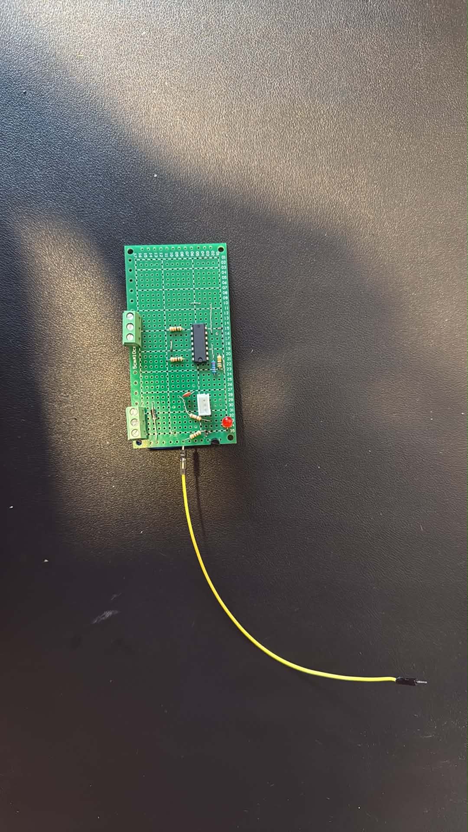
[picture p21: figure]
Không có mô tả.

Figure 16 Prototype of addition external Pump control and Wattmeter (Front view)

In Figure 15 and Figure 16, this is an integrated logical Wattmeter (no real-time display) and the logical circuit to trigger the external pump (no feedback) in Automatic mode only. However, the Wattmeter’s weakness is only applicable on the case the Voltage Require of all continuous actuators such as Pumps and Motor must be the same and DC. Concurrently, it is a protector layer to separate the AC component from dangerous mistouching.

Aside from lucid-oriented improvement, algorithm of timer should be included on the list for future operation to be automized with Machine Learning ability, choosing what best time to run and stop, rather than just a mere fixed timers so that it could optimize the operation. About power, renewable energy sources such as solar panels may be applied for optimized consumption and a replacement, in case that the household power is down. About network, it must be integrated with the module of backup mobile internet to reconnect to global control (Blynk), in case that the network provider is down.

# REFERENCES

[1] | M. Martínez-Porchas, L. R. Martínez-Córdova and R. Ramos-Enriquez, "World Aquaculture: Environmental Impacts and Troubleshooting Alternatives," The Scientific World Journal, vol. 2012, 2012.
[2] | F. a. A. O. o. t. U. Nations, "FAO Report: Global fisheries and aquaculture production reaches a new record high," 7 June 2024. [Online]. Available: https://www.fao.org/newsroom/detail/fao-report-global-fisheries-and-aquaculture-production-reaches-a-new-record-high/en.
[3] | C. T. T. S. x. T. m. T. h. T. Gia, "Những ảnh hưởng tiêu cực của ngành nuôi trồng thủy sản đến môi trường," 6 October 2020. [Online]. Available: https://luoitrangia.com/blogs/news/nhung-anh-huong-tieu-cuc-cua-nganh-nuoi-trong-thuy-san-den-moi-truong.
[4] | S. Melaku, S. Mengestou, A. Getahun, A. Geremew and A. Belay, Environmental Impacts of Wastes and Contaminants from Aquaculture and Their Remediation Techniques, IntechOpen, 2024.
[5] | T. c. T. s. V. Nam, "Phòng ngừa và khắc phục ô nhiễm nước trong nuôi thủy sản," 6 May 2025. [Online]. Available: https://thuysanvietnam.com.vn/phong-ngua-va-khac-phuc-o-nhiem-nuoc-trong-nuoi-thuy-san/.
[6] | Biogency, "Thực trạng ô nhiễm môi trường nước trong nuôi trồng thủy sản hiện nay," 30 September 2024. [Online]. Available: https://biogency.com.vn/o-nhiem-moi-truong-nuoc-trong-nuoi-trong-thuy-san/.
[7] | A. Corp, "Nuôi trồng thủy sản và những rủi ro của biến đổi khí hậu," 21 November 2023. [Online]. Available: https://atpro.com.vn/nuoi-trong-thuy-san-va-nhung-rui-ro-cua-bien-doi-khi-hau/.
[8] | F. Muhammad, M. A. Budihardjo, A. Shofwan, A. Sumartono, B. Setyawan and P. I. Nabiha, " Optimizing community-based aquaponics: Evaluating the impact of rotary drum filter implementation on water conservation and operational efficiency," E3S Web of Conferences, vol. 605, p. 03033, 2025.
[9] | K. J. de Jesus Gregersen, P. Olsson, C. Pellicer-Nàcher and P. B. Pedersen, "Effect of drum filter mesh size on RAS water quality," Aquacultural Engineering, vol. 109, p. 102508, 2025.
[10] | T. S. Rao, P. Pranay, S. Narayana, Y. Reddy, Sunil and P. Kaur, "ESP32 Based Implementation of Water Quality and Quantity Regulating System," in 3rd International Conference on Integrated Intelligent Computing Communication & Security (ICIIC 2021), 2021.
[11] | N. M. (. t. c. c. lưới, "Lưới inox 325 mesh," [Online].

# APPENDICES

The Appendices section in a report includes supplementary materials that provide additional information but are not essential to the main content. It may contain raw data, detailed calculations, extended tables, code snippets, questionnaires, or any supporting documents referenced in the report. Appendices help keep the main text concise while allowing readers to access extra details if needed. Each appendix is labelled (e.g., Appendix A, Appendix B) and referenced in the main document for clarity.

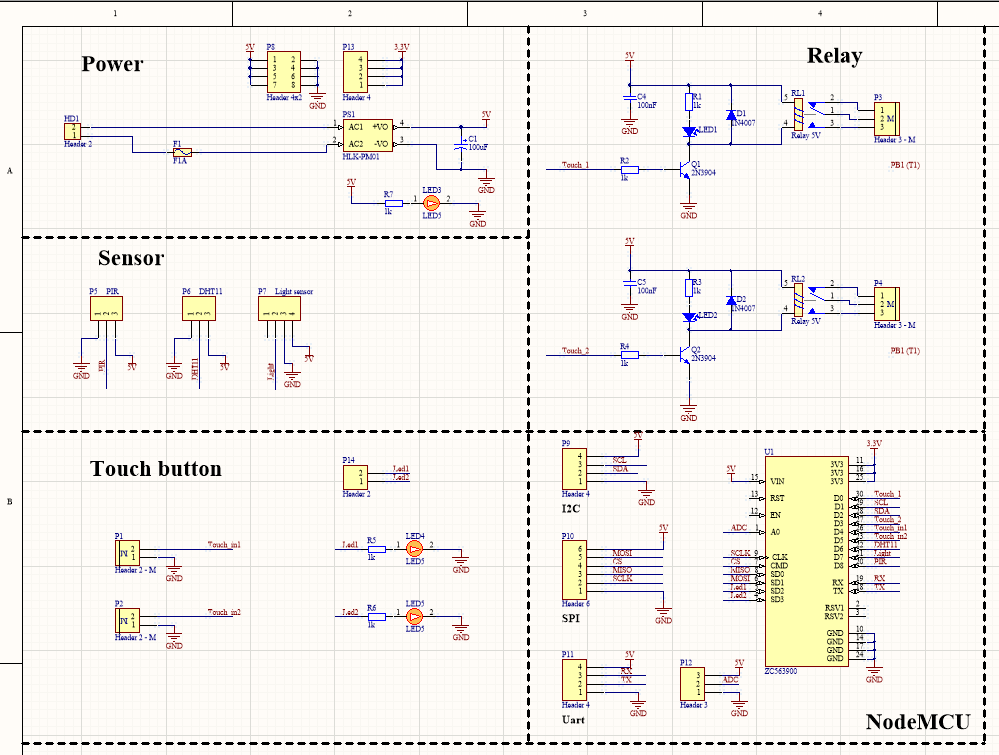
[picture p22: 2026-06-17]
ESP8266_Board/Schematic_8266.PNG

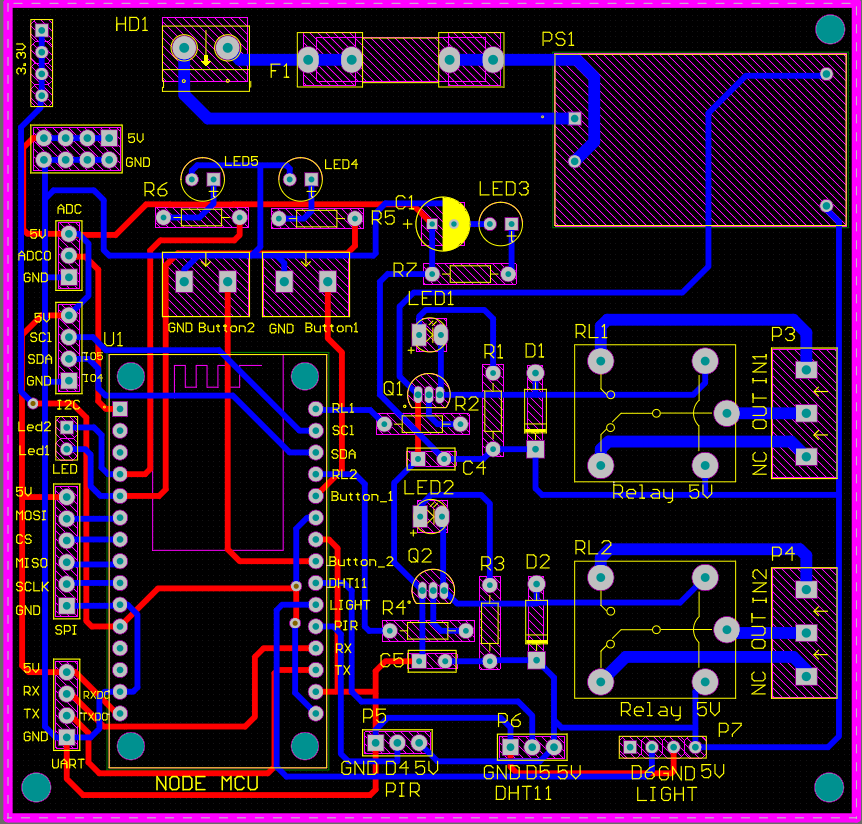
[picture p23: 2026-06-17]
ESP8266_Board/PCB_8266.PNG

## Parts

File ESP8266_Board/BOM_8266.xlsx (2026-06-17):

Comment | Description | Designator | LibRef | Quantity | Value
Cap Pol | Polarized Capacitor | C1 | Cap Pol | 1 | 100uF
Cap Non-pol | Non-polarized Capacitor | C4, C5 | Cap Non-pol | 2 | 100nF
1N4007 | Diode 1A | D1, D2 | D1A | 2 | 1N4007
F1A | Fuse | F1 | Fuse | 1 | Fuse
Header 2 | Header 2 (Green) | HD1 | Hed2 | 1 | Header 2
LED5 | LED 5mm | LED1, LED2, 'LED3, LED4, LED5 | LED 5mm | 5
Header 2 - M | Header, 2-Pin, Medium | P1, P2 | Header 2 - M | 2
Header 3 - M | Header, 3-Pin, Medium | P3, P4 | Header 3 - M | 2
PIR | Header, 3-Pin | P5, P6 | Header 3 | 1
Light sensor | Header, 4-Pin | P7 | Header 4 | 1
Header 4x2 | Header, 8-Pin, 2-Row | P8 | Header 4x2 | 1
Header 4 | Header, 4-Pin | P9, P11 | Header 4 | 2
Header 6 | Header, 6-Pin | P10 | Header 6 | 1
Header 3 | Header, 3-Pin | P12 | Header 3 | 1
Header 4 | Header, 4-Pin | P13 | Header 4 | 1
Header 2 | Header, 2-Pin | P14 | Header 2 | 1
HLK-PM01 | The HLK-PM01 is a small size low cost AC to DC converter which can take in 110V/220V AC at 50/60 Hz and give 5V 3W output. The module is can be used in designs which run on 5V and needs to be powered form the AC mains. | PS1 | HLK-PM01 | 1
2N3904 | NPN General Purpose Amplifier | Q1, Q2 | 2N3904 | 2
1k | Resistor 1/4W | R1, R2, R3, R4, R5, R6, R7 | R1/4W | 7 | R1/4W - 1K
Relay 5V | Relay SPDT,10A - 12VDC 5 Pin | RL1, RL2 | Relay 1 | 2 | Relay SPDT, 10A, 12V
ZC563900 | NodeMcu Lua ESP8266 WIFI Internet of Things Network Development Module Board | U1 | ZC563900 | 1

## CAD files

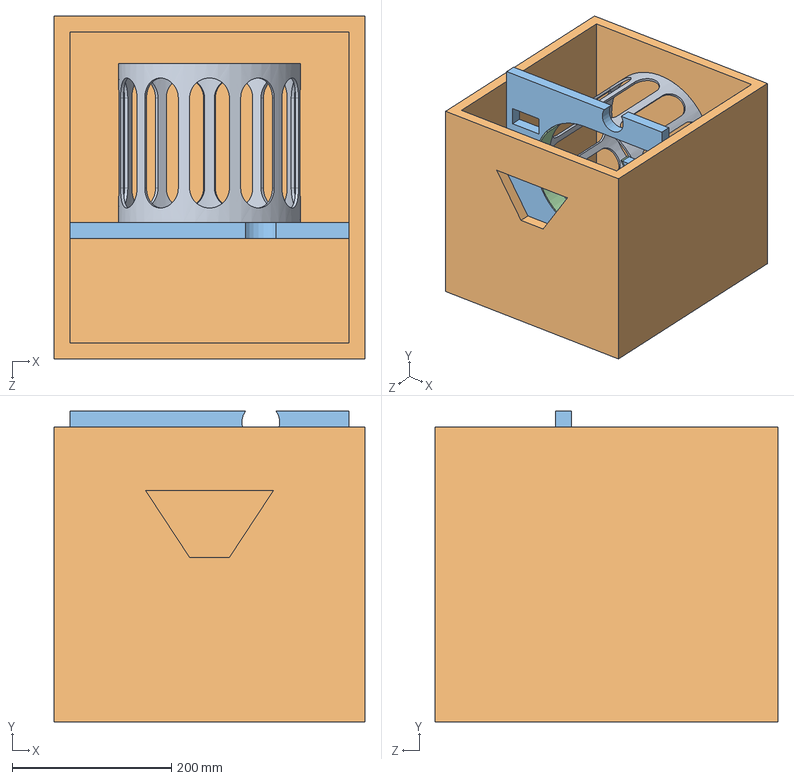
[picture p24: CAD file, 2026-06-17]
Assem1 (1).SLDASM
390.0 x 390.0 x 430.0 mm

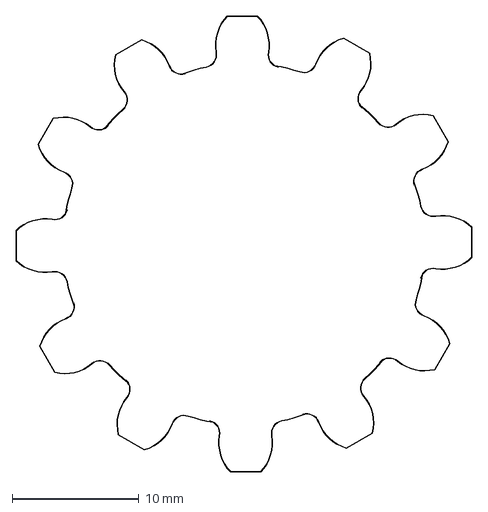
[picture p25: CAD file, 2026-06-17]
Part3.dxf
35.9 x 35.9 mm

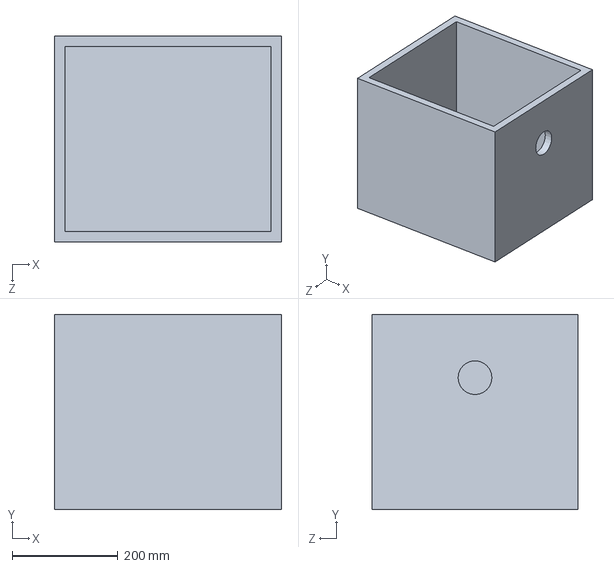
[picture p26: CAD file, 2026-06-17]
Part2.SLDPRT
430.0 x 370.0 x 390.0 mm

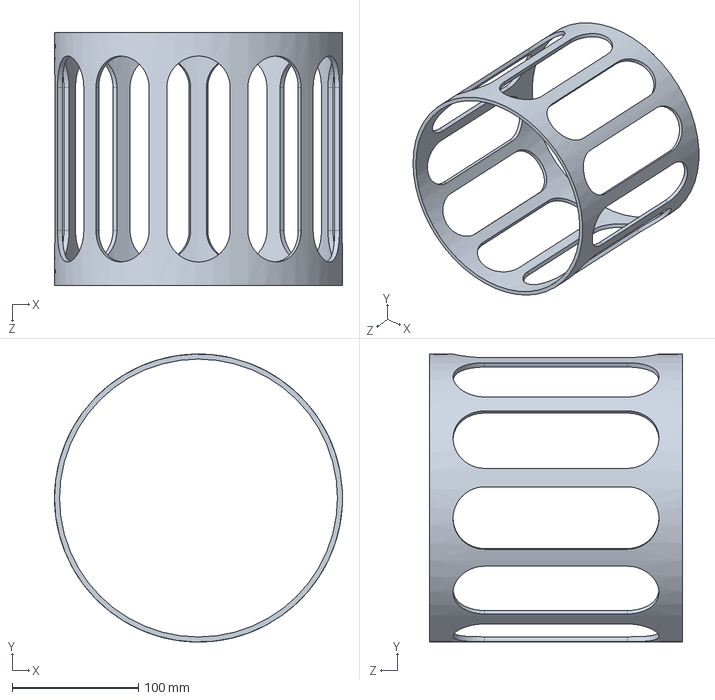
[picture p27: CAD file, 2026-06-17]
Part1.SLDPRT
228.0 x 227.9 x 200.0 mm

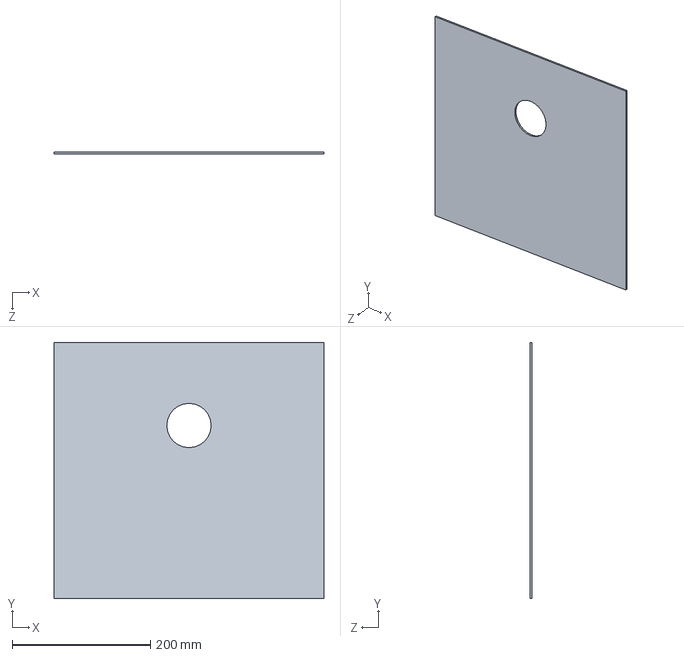
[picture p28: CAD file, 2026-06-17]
part4.SLDPRT
390.0 x 370.0 x 3.00 mm

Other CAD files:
Part6.dwg
Part3.dwg
Part4.dwg

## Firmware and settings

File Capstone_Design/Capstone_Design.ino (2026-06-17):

#define BLYNK_TEMPLATE_ID "TMPL6fDRXmB_P"
#define BLYNK_TEMPLATE_NAME "00F"
#define BLYNK_AUTH_TOKEN "tf3WvLeQhQuhK1UF3vlQBK_PLFQBvrRu"

#include <ESP8266WiFi.h>
#include <ESP8266WebServer.h>
#include <ESP8266mDNS.h>
#include <BlynkSimpleEsp8266.h>

// --- Pins ---
#define PUMP_PIN D1
#define MOTOR_PIN D2
#define FLOAT_SWITCH D5

// --- Global Objects ---
ESP8266WebServer server(80);
BlynkTimer timer;
// --- States ---
bool isPumpOn = false;
bool isMotorOn = false;
bool isAutoMode = false;
bool inConfigMode = false;
bool isConfigArmed = false;
unsigned long configArmTime = 0;
// --- Cycle Timers (in seconds) ---
long workCycleSec = 20;     // V3
long restCycleSec = 10;     // V5
long breakdownSec = 0;      // V6

unsigned long autoModeStartTime = 0;
bool isResting = false;     // Tracks if we are in the Rest Cycle

unsigned long cycleStartTime = 0;
unsigned long lastSprayToggleTime = 0;
bool sprayStateOn = false;

void loop() {
    server.handleClient();
    MDNS.update();
    timer.run();

    if (WiFi.status() == WL_CONNECTED) {
        Blynk.run();
    }

    // Switch to Config Portal after 5 seconds of being armed
    if (isConfigArmed && !inConfigMode) {
        if (millis() - configArmTime > 5000) {
            inConfigMode = true;
            isConfigArmed = false; 
        }
    }

    // --- AUTO MODE ---
 // --- AUTO MODE ---
    if (isAutoMode) {
        unsigned long now = millis();

        // 1. Breakdown Timer (V6) Check
        if (breakdownSec > 0 && (now - autoModeStartTime >= breakdownSec * 1000UL)) {
            // Time is up! Revert to Manual Mode
            isAutoMode = false;
            setMotor(false);
            setPump(false);
            
            // Sync UI back to manual state
            Blynk.virtualWrite(V2, 0); 
            Blynk.setProperty(V0, "isDisabled", false);
            Blynk.setProperty(V1, "isDisabled", false);
            Blynk.setProperty(V3, "isDisabled", true);
            Blynk.setProperty(V5, "isDisabled", true);
            Blynk.setProperty(V6, "isDisabled", true);
            return; // Exit auto logic
        }

        // 2. Water Level Override (V4)
        // Assuming FLOAT_SWITCH HIGH means LOW WATER based on your previous code
        if (digitalRead(FLOAT_SWITCH)) { 
            setMotor(false);
            setPump(false);
            return; // Pause execution until water is NORMAL
        }

        // 3. Work / Rest Cycle Logic
        unsigned long elapsedInCycle = now - cycleStartTime;

        if (!isResting) {
            // WORK CYCLE
            if (elapsedInCycle < workCycleSec * 1000UL) {
                // Motor (V1) stays ON for the entire Work Cycle
                if (!isMotorOn) setMotor(true);

                // Pump (V0) stays ON for 1/3 of the Work Cycle
                if (elapsedInCycle < (workCycleSec * 1000UL) / 3) {
                    if (!isPumpOn) setPump(true);
                } else {
                    if (isPumpOn) setPump(false);
                }
            } else {
                // Work cycle finished, transition to Rest
                isResting = true;
                cycleStartTime = now;
                setMotor(false);
                setPump(false);
            }
        } else {
            // REST CYCLE
            if (elapsedInCycle < restCycleSec * 1000UL) {
                // Keep everything OFF
                if (isMotorOn) setMotor(false);
                if (isPumpOn) setPump(false);
            } else {
                // Rest cycle finished, transition back to Work
                isResting = false;
                cycleStartTime = now;
            }
        }
    }
}
void sendFloatStatus() {
    String status = digitalRead(FLOAT_SWITCH) ? "Low" : "Normal";
        if (WiFi.status() == WL_CONNECTED) {
            Blynk.virtualWrite(V4, status);
        }
}
BLYNK_WRITE(V2) { // Mode
    isAutoMode = param.asInt();

    if (isAutoMode) {
        // AUTOMATIC MODE: Disable manual switches, enable timers
        Blynk.setProperty(V0, "isDisabled", true);
        Blynk.setProperty(V1, "isDisabled", true);
        Blynk.setProperty(V3, "isDisabled", false);
        Blynk.setProperty(V5, "isDisabled", false);
        Blynk.setProperty(V6, "isDisabled", false);

        cycleStartTime = millis();
        autoModeStartTime = millis();
        isResting = false;
    } else {
        // MANUAL MODE: Enable manual switches, disable timers
        Blynk.setProperty(V0, "isDisabled", false);
        Blynk.setProperty(V1, "isDisabled", false);
        Blynk.setProperty(V3, "isDisabled", true);
        Blynk.setProperty(V5, "isDisabled", true);
        Blynk.setProperty(V6, "isDisabled", true);

        setMotor(false);
        setPump(false);
    }
}

BLYNK_WRITE(V3) { workCycleSec = max(1, param.asInt()); } // Work Cycle
BLYNK_WRITE(V5) { restCycleSec = max(1, param.asInt()); } // Rest Cycle
BLYNK_WRITE(V6) { breakdownSec = max(0, param.asInt()); } // Breakdown Countdown

void initialise() {
    pinMode(PUMP_PIN, INPUT_PULLUP);
    delay(50);
    pinMode(PUMP_PIN, OUTPUT);
    digitalWrite(PUMP_PIN, LOW);
    pinMode(MOTOR_PIN, INPUT_PULLUP);
    delay(50);
    pinMode(MOTOR_PIN, OUTPUT);
    digitalWrite(MOTOR_PIN, LOW);
}

void setMotor(bool state) {
    digitalWrite(MOTOR_PIN, state ? HIGH : LOW);
    isMotorOn = state;
    if (WiFi.status() == WL_CONNECTED) {
        Blynk.virtualWrite(V1, state);
    }
}

void setPump(bool state) {
    digitalWrite(PUMP_PIN, state ? HIGH : LOW);
    isPumpOn = state;
    if (WiFi.status() == WL_CONNECTED) {
        Blynk.virtualWrite(V0, state);
    }
}

// =====================================================
// HTML PAGES
// =====================================================

String getConfigHTML() {
    // 1. Start building the HTML
    String html = "<!DOCTYPE html><html lang=\"en\"><head><meta charset=\"UTF-16\"><meta name=\"viewport\" content=\"width=device-width, initial-scale=1, user-scalable=no\"/><title>Drum Filter System - </title>";    html += "<style>body{text-align:center;font-family:verdana;max-width:400px;margin:0 auto;padding:20px;}div,input{padding:5px;font-size:1em;}input{width:90%;margin:5px 0;border:1px solid #ccc;border-radius:4px;box-sizing:border-box;}button{border:0;border-radius:0.3rem;background-color:#1fa3ec;color:#fff;line-height:2.4rem;font-size:1.2rem;width:100%;cursor:pointer;margin-top:15px;}button:hover{background-color:#0e70a4;}.network{display:flex;justify-content:space-between;align-items:center;padding:10px;border-bottom:1px solid #eee;}.network a{text-decoration:none;color:#1fa3ec;font-weight:bold;cursor:pointer;}.q{color:#888;font-size:0.9em;}h1{margin-bottom:5px;}</style></head>";
    html += "<body><h1>WiFiManager</h1><h3>Network Setup</h3><hr/>";

    // 2. Scan for networks
    int n = WiFi.scanNetworks();
    
    html += "<div style=\"text-align:left;\">";
    if (n == 0) {
        html += "<p style='text-align:center;'>No networks found. Please refresh.</p>";
    } else {
        // 3. Loop through results and populate the list
        for (int i = 0; i < n; ++i) {
            html += "<div class=\"network\"><a href=\"#\" onclick=\"selectSSID('";
            html += WiFi.SSID(i);
            html += "')\">";
            html += WiFi.SSID(i);
            html += "</a> <span class=\"q\">";
            html += String(WiFi.RSSI(i));
            html += " dBm ";
            html += (WiFi.encryptionType(i) == ENC_TYPE_NONE) ? "🔓" : "🔒";
            html += "</span></div>";
        }
    }
    html += "</div><br/>";

    // 4. Append the rest of the form
    html += "<form method=\"POST\" action=\"/save\">";
    html += "<label for=\"ssid\"><b>SSID</b></label><input id=\"ssid\" name=\"ssid\" length=\"32\" placeholder=\"Network Name\" value=\"\">";
    html += "<label for=\"password\"><b>Password</b></label><input id=\"password\" name=\"password\" length=\"64\" type=\"password\" placeholder=\"Password\">";
    html += "<button type=\"submit\">Save</button></form><br/>";
    html += "<button style=\"background-color:#d9534f;\" onclick=\"window.location.href='/cancel_config'\">Cancel & Return</button>";
    html += "<script>function selectSSID(ssid){document.getElementById('ssid').value=ssid;}</script></body></html>";

    return html;
}

String getDashboardHTML() {
    String water = digitalRead(FLOAT_SWITCH) ? "Low Water" : "Sufficient";
    String pumpBadge = isPumpOn ? "<span class='badge badge-on'>ON</span>" : "<span class='badge badge-off'>OFF</span>";
    String motorBadge = isMotorOn ? "<span class='badge badge-on'>ON</span>" : "<span class='badge badge-off'>OFF</span>";

    String html = "<!DOCTYPE html><html><head>";
    html += "<meta name='viewport' content='width=device-width, initial-scale=1'>";
    
    if (isConfigArmed) {
        html += "<meta http-equiv='refresh' content='5'>"; 
    }
    
    html += "<style>";
    html += "body { font-family: 'Segoe UI', Tahoma, sans-serif; background-color: #f4f7f6; color: #333; margin: 0; padding: 20px; display: flex; justify-content: center; }";
    html += ".card { background: white; border-radius: 16px; padding: 30px; box-shadow: 0 8px 24px rgba(0,0,0,0.1); max-width: 400px; width: 100%; text-align: center; }";
    html += "h2 { color: #0056b3; margin-top: 0; margin-bottom: 20px; }";
    html += ".status-box { background: #e9ecef; padding: 15px; border-radius: 12px; margin-bottom: 20px; text-align: left; }";
    html += ".status-box p { margin: 10px 0; font-weight: 500; display: flex; justify-content: space-between; align-items: center; }";
    html += ".badge { padding: 6px 12px; border-radius: 20px; font-size: 0.85em; font-weight: bold; }";
    html += ".badge-on { background: #d4edda; color: #155724; }";
    html += ".badge-off { background: #f8d7da; color: #721c24; }";
    html += ".btn-group { display: flex; justify-content: space-between; margin-bottom: 15px; gap: 10px; }";
    html += ".btn { flex: 1; padding: 12px; text-decoration: none; color: white; border-radius: 8px; font-weight: bold; transition: 0.2s; box-sizing: border-box; }";
    html += ".btn-on { background-color: #28a745; } .btn-on:hover { background-color: #218838; }";
    html += ".btn-off { background-color: #dc3545; } .btn-off:hover { background-color: #c82333; }";
    html += ".btn-action { display: block; width: 100%; padding: 14px; margin-top: 15px; text-decoration: none; color: white; border-radius: 8px; font-weight: bold; box-sizing: border-box; transition: 0.2s;}";
    html += ".btn-connect { background-color: #17a2b8; } .btn-connect:hover { background-color: #138496; }";
    html += ".btn-global { background-color: #6c757d; } .btn-global:hover { background-color: #5a6268; }";
    html += ".btn-cancel { background-color: #dc3545; animation: pulse 1s infinite; }"; 
    html += "@keyframes pulse { 0% { opacity: 1; } 50% { opacity: 0.7; } 100% { opacity: 1; } }";
    html += "</style></head><body>";

    html += "<div class='card'>";
    html += "<h2>Drum Filter Control</h2>";
    
    if (isConfigArmed) {
        html += "<div style='background-color:#fff3cd; color:#856404; padding:15px; border-radius:8px; margin-bottom:20px; border: 1px solid #ffeeba;'>";
        html += "<b>Loading...</b><br>Opening portal in 5 seconds...<br><i>Click Cancel below to abort.</i>";
        html += "</div>";
    }
    
    html += "<div class='status-box'>";
    html += "<p>Spray" + pumpBadge + "</p>";
    html += "<p>Filtration" + motorBadge + "</p>";
    html += "<p>Water Level <span><strong>" + water + "</strong></span></p>";
    html += "</div>";

    html += "<div class='btn-group'>";
    html += "<a href='/spray_on' class='btn btn-on'>Spray ON</a>";
    html += "<a href='/spray_off' class='btn btn-off'>Spray OFF</a>";
    html += "</div>";

    html += "<div class='btn-group'>";
    html += "<a href='/motor_on' class='btn btn-on'>Motor ON</a>";
    html += "<a href='/motor_off' class='btn btn-off'>Motor OFF</a>";
    html += "</div>";

    html += "<a href='/connect' class='btn-action btn-connect'>Connect & Refresh</a>";

    if (isConfigArmed) {
        html += "<a href='/global' class='btn-action btn-cancel'>Cancel Config</a>";
    } else {
        html += "<a href='/global' class='btn-action btn-global'>Global Wi-Fi Config</a>";
    }

    html += "</div></body></html>";
    return html;
}

// =====================================================
// SERVER ROUTES
// =====================================================
void setupServer() {
    server.on("/", []() { 
        if (inConfigMode) {
            server.send(200, "text/html", getConfigHTML()); // Now calls the dynamic function
        } else {
            server.send(200, "text/html", getDashboardHTML()); 
        }
    });

    server.on("/spray_on", [](){ setPump(true); server.sendHeader("Location", "/"); server.send(303); });
    server.on("/spray_off", [](){ setPump(false); server.sendHeader("Location", "/"); server.send(303); });

    server.on("/motor_on", [](){ setMotor(true); server.sendHeader("Location", "/"); server.send(303); });
    server.on("/motor_off", [](){ setMotor(false); server.sendHeader("Location", "/"); server.send(303); });

    server.on("/connect", [](){ 
        server.sendHeader("Location", "/"); 
        server.send(303); 
        ESP.restart();
        delay(10000); 
    });

    server.on("/global", []() {
        if (!inConfigMode) {
            isConfigArmed = !isConfigArmed; 
            if (isConfigArmed) {
                configArmTime = millis(); 
            }
        }
        server.sendHeader("Location", "/"); 
        server.send(303);
    });

    server.on("/cancel_config", []() {
        inConfigMode = false;
        isConfigArmed = false;
        server.sendHeader("Location", "/"); 
        server.send(303);
    });

    server.on("/save", HTTP_POST, []() {
        String ssid = server.arg("ssid");
        String pass = server.arg("password");

        Serial.println("Received WiFi Credentials:");
        Serial.println("SSID: " + ssid);
        Serial.println("PASS: " + pass);

        String responseHTML = "<!DOCTYPE html><html><head><meta name='viewport' content='width=device-width, initial-scale=1'/><meta http-equiv='refresh' content='3;url=/'><style>body{text-align:center;font-family:verdana;margin-top:50px;}</style></head><body><h2>Credentials Saved!</h2><p>Attempting to connect... returning to dashboard.</p></body></html>";
        server.send(200, "text/html", responseHTML);

        inConfigMode = false; 
        isConfigArmed = false;

        WiFi.begin(ssid, pass);
    });

    server.begin();
}

// =====================================================
// SETUP
// =====================================================
void setup() {
    Serial.begin(115200);
    pinMode(PUMP_PIN, OUTPUT);
    pinMode(FLOAT_SWITCH, INPUT_PULLUP);
    digitalWrite(PUMP_PIN, LOW);

    initialise(); 

    // Setup WiFi as Access Point & Station
    WiFi.mode(WIFI_AP_STA);
    WiFi.softAP("Drum Filter System Configuration", "V1im3n3t43r3o3");
    
    if (MDNS.begin("drumfilter")) {
        Serial.println("MDNS responder started");
    }

    Blynk.config(BLYNK_AUTH_TOKEN);

    timer.setInterval(2000L, sendFloatStatus);
    setupServer();
}
